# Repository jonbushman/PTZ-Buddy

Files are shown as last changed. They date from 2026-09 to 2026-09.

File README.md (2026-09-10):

# PTZ Buddy

Raspberry Pi + PCA9685 + two MG995 servos, driven by a Bluetooth gamepad's
left stick, for a DIY pan/tilt camcorder mount (built around a Canon
Vixia HF R600/R800). This covers pan/tilt only - the Vixia has no LANC
port, so zoom/record stay manual (or a future IR-blaster hack) rather
than motorized.

## Wiring

- **PCA9685** on the Pi's I2C bus (`SDA`/`SCL`, plus 3.3V logic power and
  ground). Enable I2C first: `sudo raspi-config` -> Interface Options -> I2C.
- **Servo power (V+ on the PCA9685 terminal block)** comes from a separate
  5-6V, 3A+ supply - NOT the Pi's 5V rail. Two MG995s can still pull close
  to 1A each under load; sharing the Pi's supply causes brownouts and
  random reboots. Tie the servo supply's ground to the Pi's ground.
- Pan servo -> PCA9685 channel 0, tilt servo -> channel 1 (see `config.py`
  if you wire them differently).

## Bluetooth gamepad pairing

```
sudo bluetoothctl
power on
agent on
scan on          # find your controller's MAC, then:
scan off
pair   <MAC>
trust  <MAC>
connect <MAC>
```

Confirm it shows up with `ls /dev/input/` and run `evtest` against it once
to check which `ABS_*` codes the left stick reports - most report
`ABS_X`/`ABS_Y`, but some (Switch Pro-style controllers especially) use
`ABS_RX`/`ABS_RY` instead. Update `AXIS_PAN`/`AXIS_TILT` in
`gamepad_input.py` if needed.

## Setup

```
pip install -r requirements.txt
python3 ptz_service.py   # bench test with the gamepad connected
```

Tune `config.py` before your first live test:
- `PAN_MIN_DEG`/`PAN_MAX_DEG`/`TILT_MIN_DEG`/`TILT_MAX_DEG` - set these to
  match your bracket's actual safe range of motion, with margin so the
  camera can't hit its own mount or cabling.
- `PAN_MAX_SPEED`/`TILT_MAX_SPEED` and `*_ACCEL` - how fast/snappy the rig
  feels under stick input.
- `TILT_COMPENSATION` - see below.

To run on boot:

```
sudo cp ptz-controller.service /etc/systemd/system/
sudo systemctl enable --now ptz-controller
```

## The "curving pan" fix

Panning at a fixed angular rate while tilted off level causes a diagonal
stick move to trace a visible curve on screen instead of a straight line -
this is a known artifact on two-axis pan/tilt heads, and professional PTZ
cameras counter it with "tilt-compensated pan speed": the pan rate is
scaled down as tilt moves away from level. `servo_controller.py` implements
a first-pass version of this (`PanTiltRig._tilt_compensation_factor`,
tuned via `config.TILT_COMPENSATION`). The right amount of compensation
depends on your lens FOV and zoom level, so expect to tune it by eye on
camera rather than trusting the default.

## 3D-printed bracket

See `cad/README.md` for the parametric pan/tilt bracket (OpenSCAD source,
STLs, and assembly instructions) that carries the camcorder on these two
servos.

## Future ideas

The control loop is intentionally split into small pieces
(`Gamepad`, `Axis`, `PanTiltRig`) so later additions can hook in without a
rewrite - preset positions, a network/websocket control surface (e.g. tied
into OBS or Overlay-Buddy for automated camera cuts), or recording gamepad
moves for playback.

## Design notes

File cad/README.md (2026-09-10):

# PTZ Buddy bracket (3D-printable)

Five parts, parametric in `ptz_bracket.scad` (OpenSCAD, free): `base_plate`,
`pan_platform`, `tilt_wall`, `idler_wall`, `camera_plate`. STLs are in `stl/`,
preview renders in `renders/` (`assembly.png` shows how they go together -
it's a rough visualization only, not how the parts are oriented for
printing; each part is already modeled flat-on-the-bed for its own STL).

## Before you print anything

The dimensions in the `MEASURE ME` block at the top of `ptz_bracket.scad`
are sized for a Deegoo-FPV MG995 (standard MG995/MG996R case footprint)
and a 608 skate bearing, but real parts vary by +/-0.5mm between brands,
and `shaft_z_offset` in particular is an estimate (no verified dimensioned
drawing was available for this one). Measure your actual servos with
calipers (case length/width/height, and how high the output shaft sits
above the case bottom) and update the constants before committing to a
full print. Print just `base_plate` first (smallest, fastest) and
test-fit your servo in its cradle before printing the rest.

To change a value and re-export, edit the constant and run, e.g.:

```
openscad -D 'part="tilt_wall"' -o stl/tilt_wall.stl ptz_bracket.scad
```

## How it goes together

- **base_plate**: sits on your tripod's quick-release plate. The QR
  plate's own screw threads up into a trapped 1/4"-20 hex nut underneath.
  The pan servo sits in a shallow locating fence on top (shaft pointing
  up) and is held down with two zip-ties routed through the slots on
  either side, over the servo's flange - this is deliberately tolerant of
  exact flange-hole spacing, which varies between servo brands.
- **pan_platform**: a disc that bolts to the pan servo's own round horn
  (through the horn's existing screw holes - `horn_bcd`/`horn_hole_count`
  need to match yours). It carries `tilt_wall` and `idler_wall`, bolted
  down near its edge with M3 self-tapping screws into the pilot holes,
  `axle_span` apart.
- **tilt_wall**: cradles the tilt servo the same way the base plate
  cradles the pan servo (snug pocket + zip-ties over the top), with the
  output shaft poking through a hole partway up, aimed at `camera_plate`.
- **idler_wall**: a passive support directly opposite the tilt servo. A
  608 bearing press-fits into its pocket; don't skip this side - a
  camcorder cantilevered off the servo shaft alone will sag and wobble
  over a multi-hour stream.
- **camera_plate**: the cradle that actually holds the camera. One end
  bolts to a horn on the tilt servo's shaft; the other end bolts to an M8
  bolt that passes through the idler bearing's inner race (the bearing's
  outer race stays pressed into `idler_wall`). The deck has a counterbored
  hole for a standard tripod mounting screw, which threads up into the
  camcorder's own threaded socket.

## Hardware you'll need per rig

- 2x MG995 servo (you already have these) + their stock round horns
- 1x 608 bearing (skateboard bearing, ~$2)
- 1x M8x20mm bolt + nut (idler axle)
- Small M3 self-tapping screws (mounting the walls to the pan platform)
- Small M2/M2.5 self-tapping screws (bolting the horns to pan_platform /
  camera_plate through the horn's own arm holes)
- 2-4 small zip ties
- 1x 1/4"-20 hex nut (base plate)
- A standard tripod quick-release plate (its screw becomes the base
  plate's mounting screw) and a standard 1/4"-20 tripod mounting screw
  for the camera_plate deck

## Print settings

- Material: PETG or ASA, not PLA - `tilt_wall`/`idler_wall`/`camera_plate`
  carry a cantilevered load for hours at a time and PLA creeps under
  sustained stress.
- Infill: 30-40% for `tilt_wall`, `idler_wall`, `camera_plate`; 20% is
  fine for `base_plate` and `pan_platform`.
- Orientation: all five parts are already modeled to print flat on the bed
  with no supports needed (open pockets/cavities face up).
- Test-fit `base_plate`'s servo cradle and the 1/4"-20 nut trap before
  printing everything else - if your nut or servo don't match the
  defaults, it's a 5-minute reprint instead of finding out after printing
  all five parts.

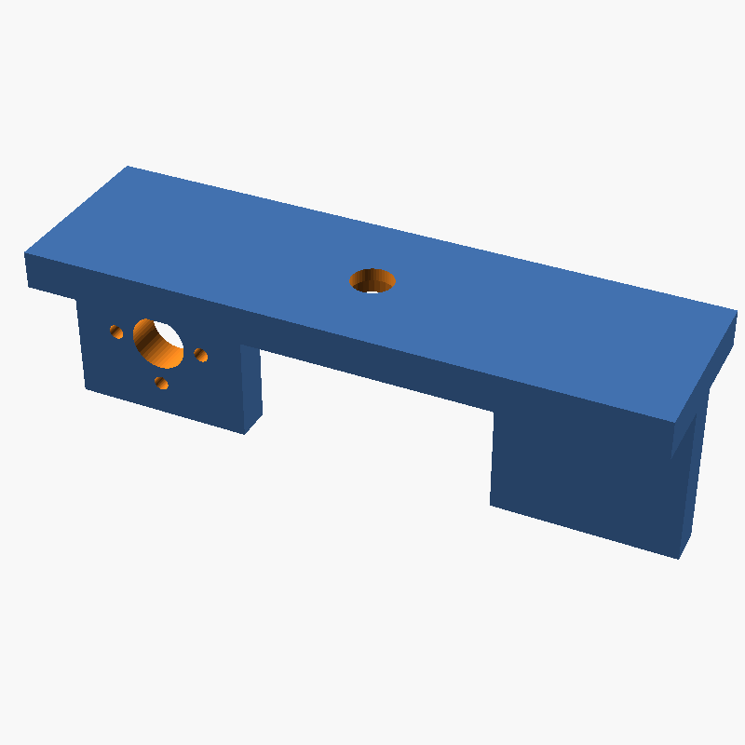
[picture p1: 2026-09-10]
cad/renders/camera_plate.png

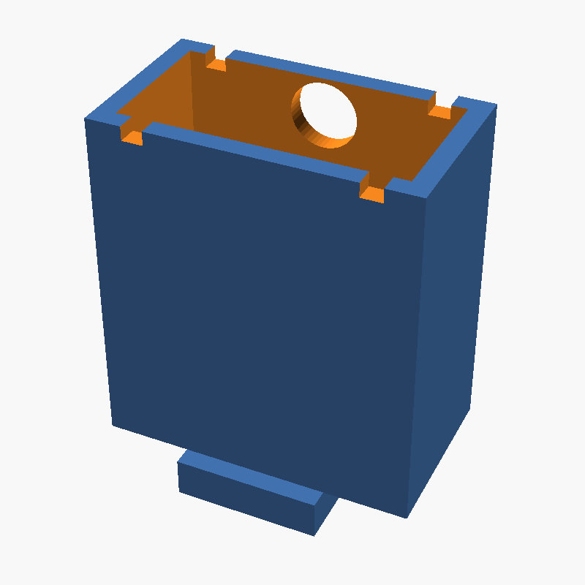
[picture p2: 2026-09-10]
cad/renders/tilt_wall.png

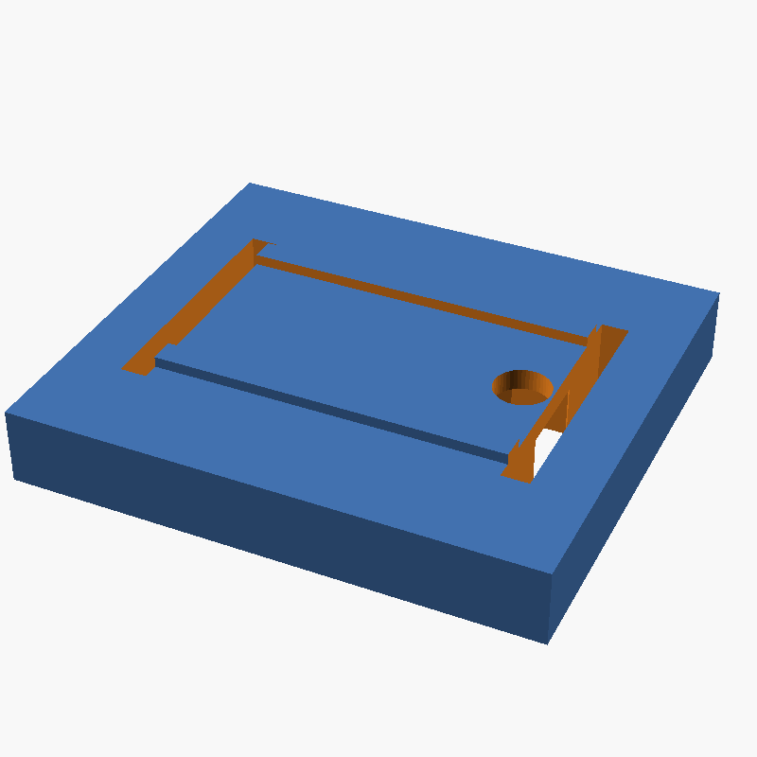
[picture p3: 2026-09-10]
cad/renders/base_plate.png

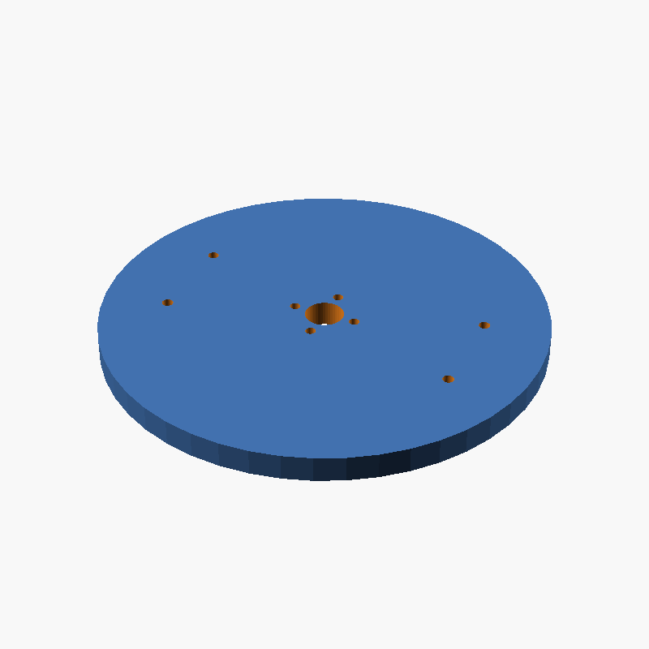
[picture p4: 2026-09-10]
cad/renders/pan_platform.png

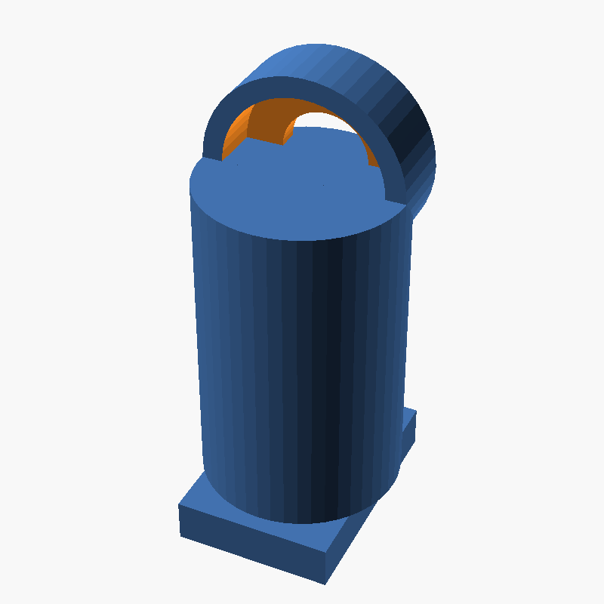
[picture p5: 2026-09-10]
cad/renders/idler_wall.png

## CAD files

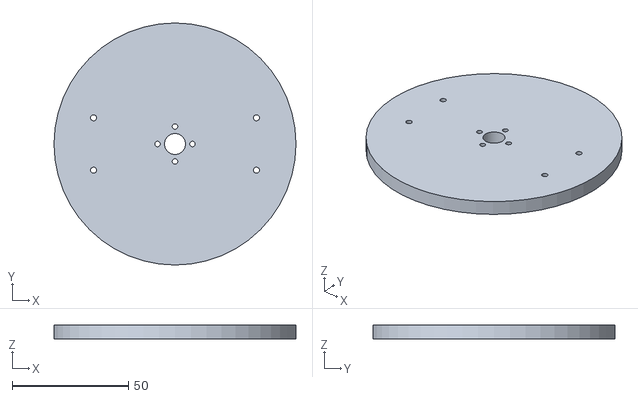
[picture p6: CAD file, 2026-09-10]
cad/stl/pan_platform.stl
104.0 x 104.0 x 6.00

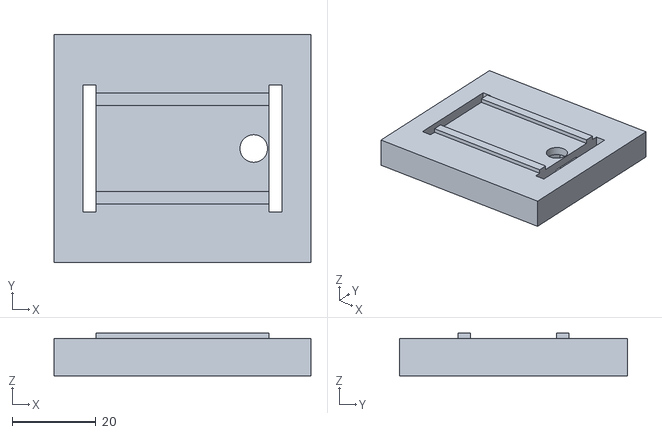
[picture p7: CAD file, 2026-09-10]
cad/stl/base_plate.stl
61.5 x 54.5 x 10.2

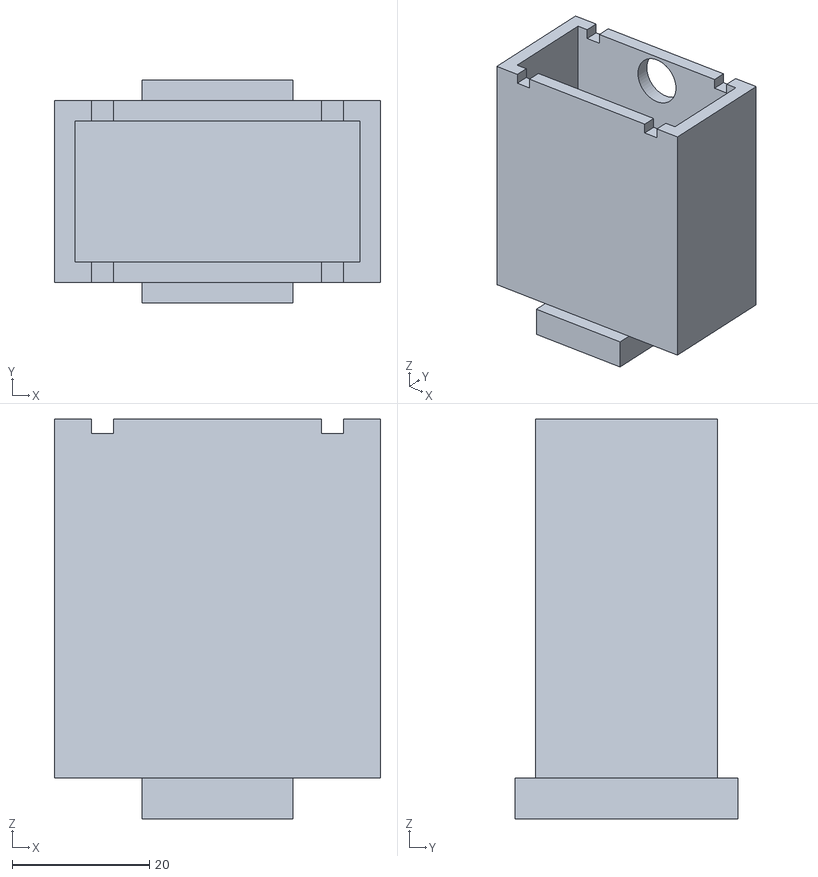
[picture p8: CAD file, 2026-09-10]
cad/stl/tilt_wall.stl
47.5 x 32.5 x 58.2

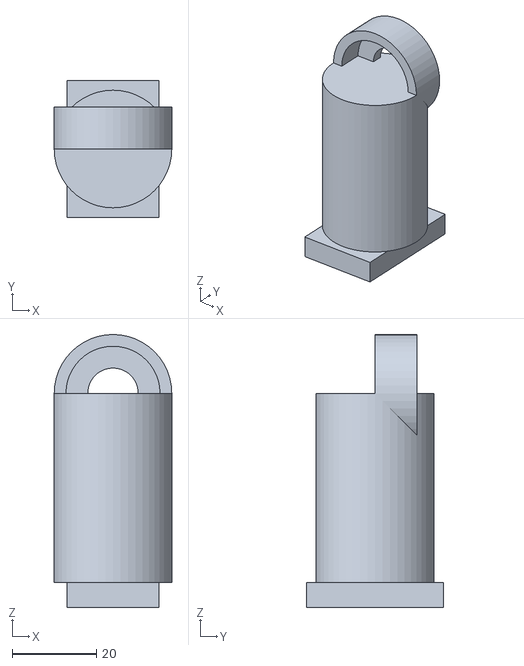
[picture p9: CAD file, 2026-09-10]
cad/stl/idler_wall.stl
28.0 x 32.5 x 65.0

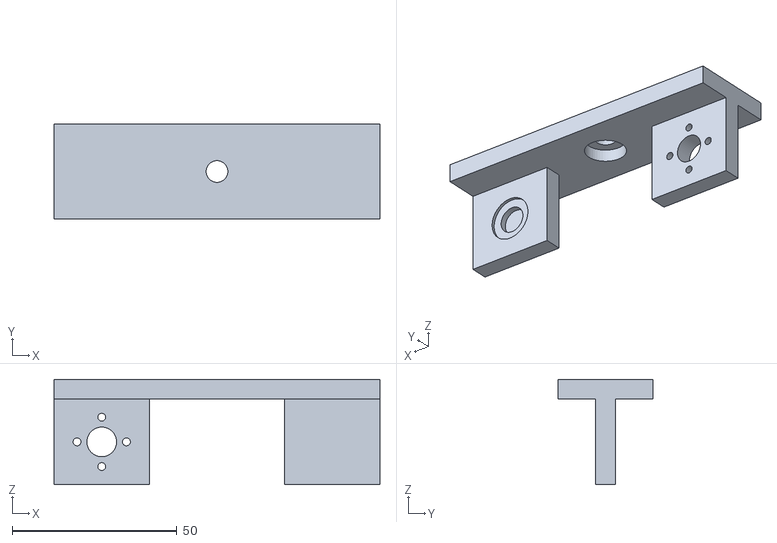
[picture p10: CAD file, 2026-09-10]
cad/stl/camera_plate.stl
99.0 x 29.0 x 32.0

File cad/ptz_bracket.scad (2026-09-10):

// ============================================================
// PTZ Buddy - pan/tilt camera bracket (parametric OpenSCAD)
// ============================================================
// Five printed parts: base_plate, pan_platform, tilt_wall,
// idler_wall, camera_plate. See ../README.md for assembly,
// hardware (screws/bearing/servos), and print settings.
//
// *** MEASURE YOUR ACTUAL SERVOS AND BEARING WITH CALIPERS AND
// *** UPDATE THE "MEASURE ME" BLOCK BELOW BEFORE PRINTING.
// Defaults below are sized for a Deegoo-FPV MG995 (standard MG995/MG996R
// case footprint, 13kg-cm/6V) and a 608 skate bearing, but real parts
// vary by +/-0.5mm between brands - print a single wall or the base
// plate first and test-fit before committing a full print run.
// shaft_z_offset especially is an estimate (no verified dimensioned
// drawing was available) - measure yours before trusting it.

$fn = 48;

// ---------------- MEASURE ME ----------------
servo_body_l    = 40.7;  // servo case length, long axis (shaft end to back)
servo_body_w    = 19.7;  // servo case width
servo_body_h    = 42.9;  // servo case height (bottom of case to top, under horn)
shaft_z_offset  = 38.0;  // height of the output shaft centerline above the
                          // case bottom - estimated, not from a verified
                          // drawing. Most servos have it near the top, not
                          // centered - measure this one carefully.

horn_bcd        = 15.0;  // bolt circle diameter of the round horn's own screw holes.
                          // MG995 kits usually include a round horn with
                          // several concentric hole rings - measure the
                          // ring you plan to use and match its diameter here.
horn_hole_dia   = 2.4;   // diameter of those holes (for M2/M2.5 self-tap screws)
horn_hole_count = 4;
horn_boss_dia   = 9.0;   // clearance for the horn's center hub + screw head

bearing_od      = 22.0;  // 608 bearing outer diameter
bearing_id      = 8.0;   // 608 bearing bore -> also the idler axle bolt size (M8)
bearing_thick   = 7.0;

tripod_nut_af     = 11.4; // 1/4"-20 hex nut, across-flats + a bit of print clearance
tripod_nut_thick  = 6.5;
tripod_screw_dia  = 6.6;  // clearance for a 1/4" tripod screw shaft
tripod_head_dia   = 13.0; // typical tripod mounting screw head diameter
tripod_head_recess = 4.0;
// ---------------------------------------------

// ---------------- fit / build ----------------
clr        = 0.4;   // per-side clearance on body pockets
wall_t     = 3;     // shell thickness around a pocket
plate_t    = 6;     // flat structural plate thickness
base_t     = 9;     // base plate thickness (must clear tripod_nut_thick + roof)
zip_w      = 3.2;   // zip-tie slot width
axle_span  = 70;    // tilt-servo shaft to idler-shaft distance (world X)
yoke_h     = 45;    // height of the tilt/idler rotation axis above the
                     // pan-platform disc's top face
foot_l     = 22;    // wall bracket foot length (X)
foot_w     = servo_body_w + 2*clr + 2*wall_t + 6;  // foot width (Y)
pan_disc_d = axle_span + foot_l + 12;
pilot_dia  = 2.6;   // pilot hole for self-tapping M3 mounting screws
leg_h      = 26;    // camera_plate end-leg height (axis sits at leg_h/2)
leg_w      = horn_bcd + 14;
// ---------------------------------------------

part = "assembly"; // overridden from the command line for STL export:
                    // base_plate | pan_platform | tilt_wall | idler_wall | camera_plate

module horn_bolt_pattern(bcd, count) {
    for (i = [0:count-1])
        rotate([0,0, i*360/count])
            translate([bcd/2, 0, 0])
                children();
}

module hex_prism(af, h) {
    r = af / cos(30) / 2;
    cylinder(r = r, h = h, $fn = 6);
}

// Cut from a face at local z=0, growing in +z: hex pocket for a 1/4"-20
// nut, then a narrower clearance hole continuing up for the screw's tip.
module tripod_nut_trap() {
    translate([0,0,-0.01]) hex_prism(tripod_nut_af, tripod_nut_thick + 0.01);
    translate([0,0, tripod_nut_thick - 0.01]) cylinder(d = tripod_screw_dia, h = 50);
}

// Cut from the bottom face (local z=0) upward: a counterbore for a
// standard tripod mounting screw's head, then a narrower clearance hole
// continuing up so the screw's threads reach the camcorder's own
// threaded socket above. (Unlike tripod_nut_trap, we're not supplying
// the female thread here - the camcorder already has one.)
module tripod_screw_counterbore() {
    translate([0,0,-0.01]) cylinder(d = tripod_head_dia, h = tripod_head_recess + 0.01);
    translate([0,0, tripod_head_recess - 0.01]) cylinder(d = tripod_screw_dia, h = 50);
}

// A horn mount: center clearance hole + bolt-circle holes, cut through
// a plate of thickness h starting at local z=0.
module horn_mount_holes(h) {
    translate([0,0,-0.1]) cylinder(d = horn_boss_dia, h = h + 0.2);
    horn_bolt_pattern(horn_bcd, horn_hole_count)
        translate([0,0,-0.1]) cylinder(d = horn_hole_dia, h = h + 0.2);
}

// ---------------- base_plate ----------------
// Sits on the tripod's quick-release plate (its screw threads up into the
// trapped nut here). The pan servo sits on TOP of this plate (its shaft
// points straight up into the pan_platform's horn) inside a shallow
// locating fence, held down by two zip-ties routed through slots.
module base_plate() {
    sl = servo_body_l + 2*clr;
    sw = servo_body_w + 2*clr;
    plate_l = sl + 2*wall_t + 14;
    plate_w = sw + 2*wall_t + 28;
    tripod_x = plate_l/2 - tripod_nut_af/2 - 8;
    fence_h = 2.5;

    difference() {
        union() {
            cube([plate_l, plate_w, base_t], center = true);
            translate([0,0, base_t/2])
                difference() {
                    cube([sl + 2*wall_t, sw + 2*wall_t, fence_h], center = true);
                    translate([0,0,0.1]) cube([sl, sw, fence_h + 0.2], center = true);
                }
        }

        translate([tripod_x, 0, -base_t/2 - 0.01]) tripod_nut_trap();

        for (x = [-sl/2 - wall_t/2, sl/2 + wall_t/2])
            translate([x, 0, 0]) cube([zip_w, sw + 10, base_t + fence_h + 1], center = true);
    }
}

// ---------------- pan_platform ----------------
// Disc bolted to the pan servo's own round horn; carries the tilt_wall
// and idler_wall L-brackets bolted near its edge, axle_span apart.
module pan_platform() {
    difference() {
        cylinder(d = pan_disc_d, h = plate_t);
        horn_mount_holes(plate_t);
        for (side = [-1, 1])
            translate([side * axle_span/2, 0, 0])
                for (y = [-foot_w/2 + 5, foot_w/2 - 5])
                    translate([0, y, -0.1]) cylinder(d = pilot_dia, h = plate_t + 0.2);
    }
}

// ---------------- L-bracket foot (shared) ----------------
module l_bracket_foot() {
    difference() {
        cube([foot_l, foot_w, plate_t], center = true);
        for (y = [-foot_w/2 + 5, foot_w/2 - 5])
            translate([0, y, -0.1]) cylinder(d = pilot_dia, h = plate_t + 0.2);
    }
}

// ---------------- tilt_wall ----------------
// Foot at z=[-plate_t/2, plate_t/2] (bolts to pan_platform). A box rises
// above it cradling the tilt servo; the servo's shaft hole (and thus the
// tilt rotation axis) lands at world z = plate_t/2 + yoke_h, pointing
// along +Y toward where the camera_plate attaches.
module tilt_wall() {
    box_w = servo_body_w + 2*clr + 2*wall_t;
    box_l = servo_body_l + 2*clr + 2*wall_t;
    box_h = servo_body_h + 2*clr + wall_t;
    // z of the servo cavity's floor (world, foot top = plate_t/2)
    box_z0 = plate_t/2 + yoke_h - shaft_z_offset - wall_t/2;
    // one continuous solid from the foot top up through the cradle, so
    // there's no floating gap between the foot and the servo box
    solid_h = box_z0 + box_h - plate_t/2;

    union() {
        l_bracket_foot();
        translate([0,0, plate_t/2])
            difference() {
                translate([0,0, solid_h/2]) cube([box_l, box_w, solid_h], center = true);

                // servo body cavity, open top
                translate([0,0, (box_z0 - plate_t/2) + wall_t + (servo_body_h + 2*clr)/2])
                    cube([servo_body_l + 2*clr, servo_body_w + 2*clr, servo_body_h + 2*clr + 1], center = true);

                // shaft clearance, exits the +Y face toward the camera_plate
                translate([0, box_w/2 - wall_t - 0.1, (box_z0 - plate_t/2) + wall_t + shaft_z_offset])
                    rotate([-90,0,0]) cylinder(d = 10, h = wall_t + 0.3);

                // zip-tie slots across the open top, front-to-back
                for (x = [-box_l/2 + 7, box_l/2 - 7])
                    translate([x, 0, solid_h - 0.1]) cube([zip_w, box_w + 6, 4], center = true);
            }
    }
}
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

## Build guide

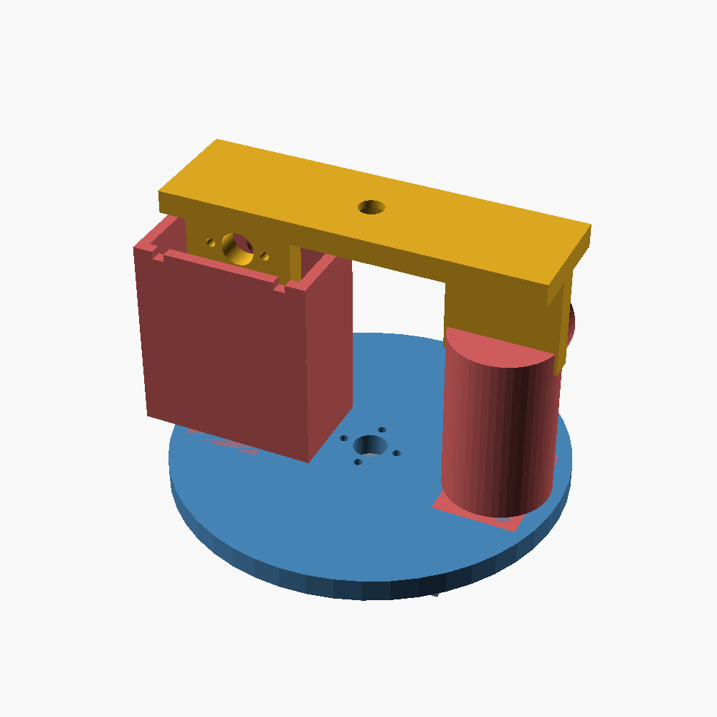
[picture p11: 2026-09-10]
cad/renders/assembly.png

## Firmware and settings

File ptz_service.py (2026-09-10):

"""Main control loop: gamepad input -> smoothed pan/tilt servo motion.

Run directly for bench testing, or install ptz-controller.service to
start automatically on boot.
"""
import time

import config
from gamepad_input import Gamepad
from servo_controller import PanTiltRig


def main():
    rig = PanTiltRig()
    pad = Gamepad()
    print(f"Gamepad connected: {pad.device.name}")

    period = 1.0 / config.LOOP_HZ
    last = time.monotonic()

    while True:
        now = time.monotonic()
        dt = now - last
        last = now

        pan_stick, tilt_stick = pad.poll()
        rig.step(pan_stick, tilt_stick, dt)

        sleep_left = period - (time.monotonic() - now)
        if sleep_left > 0:
            time.sleep(sleep_left)


if __name__ == "__main__":
    main()

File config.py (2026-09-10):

"""PTZ rig configuration - tune these for your hardware and lens FOV."""

# PCA9685 channels
PAN_CHANNEL = 0
TILT_CHANNEL = 1

# Servo pulse range (microseconds). 500/2500 is a safe wide default for
# MG995-style digital servos; narrow it if your servos buzz at the
# extremes instead of stopping cleanly.
SERVO_MIN_US = 500
SERVO_MAX_US = 2500

# Mechanical travel limits, degrees. Keep inside the servo's rated 180 deg
# and leave margin so the camera can't crash into the bracket or its own
# cabling.
PAN_MIN_DEG = 10
PAN_MAX_DEG = 170
TILT_MIN_DEG = 45
TILT_MAX_DEG = 135
TILT_LEVEL_DEG = 90  # tilt angle that corresponds to a level horizon

# Starting position on boot / home command
PAN_HOME_DEG = 90
TILT_HOME_DEG = 90

# Max angular speed, degrees/second, at full stick deflection
PAN_MAX_SPEED = 60.0
TILT_MAX_SPEED = 40.0

# Accel/decel ramp, degrees/second^2 - this is what keeps whip-pans smooth
# on stream instead of snapping instantly to full speed
PAN_ACCEL = 120.0
TILT_ACCEL = 90.0

# Tilt-compensated pan speed: broadcast PTZ heads slow the pan rate as tilt
# moves away from level so a diagonal move traces a straight line on screen
# instead of a visible curve. 1.0 = full compensation, 0.0 = disabled.
# Depends on your lens FOV/zoom, so expect to tune this by eye on camera.
TILT_COMPENSATION = 1.0

# Joystick deadzone (0-1) to stop drift-induced creep
STICK_DEADZONE = 0.08

# Control loop rate, Hz
LOOP_HZ = 50

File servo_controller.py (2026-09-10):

"""Smooth-motion pan/tilt servo driver on a PCA9685 I2C board."""
import math

import board
import busio
from adafruit_motor import servo
from adafruit_pca9685 import PCA9685

import config


class Axis:
    """One servo axis with velocity-ramped, angle-limited motion.

    Motion is driven by target speed rather than target angle so the
    control loop can ramp acceleration smoothly frame to frame instead of
    snapping the servo straight to a commanded position.
    """

    def __init__(self, pca_channel, min_deg, max_deg, home_deg, max_speed, accel):
        self._servo = servo.Servo(
            pca_channel, min_pulse=config.SERVO_MIN_US, max_pulse=config.SERVO_MAX_US
        )
        self.min_deg = min_deg
        self.max_deg = max_deg
        self.max_speed = max_speed
        self.accel = accel
        self.angle = home_deg
        self.velocity = 0.0
        self._servo.angle = self.angle

    def update(self, target_speed, dt):
        """Ramp velocity toward target_speed (deg/s) and integrate angle."""
        target_speed = max(-self.max_speed, min(self.max_speed, target_speed))
        max_delta = self.accel * dt
        if target_speed > self.velocity:
            self.velocity = min(target_speed, self.velocity + max_delta)
        else:
            self.velocity = max(target_speed, self.velocity - max_delta)

        new_angle = self.angle + self.velocity * dt
        clamped = max(self.min_deg, min(self.max_deg, new_angle))
        if clamped != new_angle:
            self.velocity = 0.0  # hit a mechanical limit - stop dead, don't push
        self.angle = clamped
        self._servo.angle = self.angle

    def set_angle_immediate(self, angle_deg):
        self.angle = max(self.min_deg, min(self.max_deg, angle_deg))
        self.velocity = 0.0
        self._servo.angle = self.angle


class PanTiltRig:
    def __init__(self):
        i2c = busio.I2C(board.SCL, board.SDA)
        self.pca = PCA9685(i2c)
        self.pca.frequency = 50

        self.pan = Axis(
            self.pca.channels[config.PAN_CHANNEL],
            config.PAN_MIN_DEG,
            config.PAN_MAX_DEG,
            config.PAN_HOME_DEG,
            config.PAN_MAX_SPEED,
            config.PAN_ACCEL,
        )
        self.tilt = Axis(
            self.pca.channels[config.TILT_CHANNEL],
            config.TILT_MIN_DEG,
            config.TILT_MAX_DEG,
            config.TILT_HOME_DEG,
            config.TILT_MAX_SPEED,
            config.TILT_ACCEL,
        )

    def _tilt_compensation_factor(self):
        """Scale factor for pan speed based on how far off level the tilt is.

        See config.TILT_COMPENSATION for the reasoning - this is what
        prevents a diagonal stick move from curving across the frame.
        """
        offset = math.radians(self.tilt.angle - config.TILT_LEVEL_DEG)
        factor = math.cos(offset)
        return 1.0 - config.TILT_COMPENSATION * (1.0 - factor)

    def step(self, pan_stick, tilt_stick, dt):
        """pan_stick/tilt_stick are normalized gamepad axes in [-1, 1]."""
        pan_speed = pan_stick * self.pan.max_speed * self._tilt_compensation_factor()
        tilt_speed = tilt_stick * self.tilt.max_speed
        self.pan.update(pan_speed, dt)
        self.tilt.update(tilt_speed, dt)

    def home(self):
        self.pan.set_angle_immediate(config.PAN_HOME_DEG)
        self.tilt.set_angle_immediate(config.TILT_HOME_DEG)

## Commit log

2026-09-10 Initial PTZ Buddy: Raspberry Pi PTZ camera rig controller
    Gamepad-driven pan/tilt control for a servo-based camcorder mount:
    PCA9685 servo driver, evdev Bluetooth stick input, velocity-ramped
    smooth motion, and tilt-compensated pan speed to avoid the curved
    pan artifact seen on combined pan/tilt moves.
    Claude-Session: https://claude.ai/code/session_012JKCLHDaWgU7KALHoZ1kCQ
    [config.py, gamepad_input.py, ptz_service.py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]
2026-09-10 Add parametric 3D-printable pan/tilt bracket
    Five-part OpenSCAD design: base_plate (tripod mount + pan servo cradle),
    pan_platform (bolts to the pan servo's horn), tilt_wall and idler_wall
    (the yoke, with a 608 bearing opposite the tilt servo so the camcorder
    isn't cantilevered off the servo shaft alone), and camera_plate (the
    cradle that holds the camcorder). Servos are held with zip-tie cradles
    rather than exact flange-hole bolting since hole spacing varies between
    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
    [base_plate.stl, camera_plate.stl, idler_wall.stl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]
2026-09-10 Correct bracket and docs for actual hardware: MG995 servos, Osmo Action
    Update servo dimensions in the CAD model from an assumed 20kg DS3218 to
    the Deegoo-FPV MG995 the user actually has (40.7x19.7x42.9mm case);
    shaft_z_offset is flagged as an estimate since no verified dimensioned
    drawing was available.
    The camera is a DJI Osmo Action 4/5, not a Vixia camcorder - it has no
    tripod thread or LANC port of its own. camera_plate's tripod screw now
    threads into a cheap GoPro-mount-to-1/4"-20 adapter clipped to the
    Osmo's Quick-Release Adapter Mount, documented in cad/README.md.
    Claude-Session: https://claude.ai/code/session_012JKCLHDaWgU7K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
    [base_plate.stl, camera_plate.stl, idler_wall.stl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]
2026-09-10 Revert camera choice to the Vixia camcorder
    Weighed the Osmo Action vs. Vixia HF R600/R800 tradeoffs: the Osmo's
    only real advantage was rig weight, which the MG995 servos have ample
    torque margin for regardless. The Vixia's real optical zoom, lack of
    lens distortion, and suitability for continuous multi-hour operation
    outweigh the Osmo's lighter body and skip-the-capture-card convenience
    (a capture card is already on hand). No GoPro adapter needed - the
    camera_plate mount already assumed a camcorder's own tripod socket.
    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
    [ptz_bracket.scad]
